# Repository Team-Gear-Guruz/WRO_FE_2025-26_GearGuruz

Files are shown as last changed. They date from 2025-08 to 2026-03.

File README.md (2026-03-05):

Engineering material
====

<p align="center">
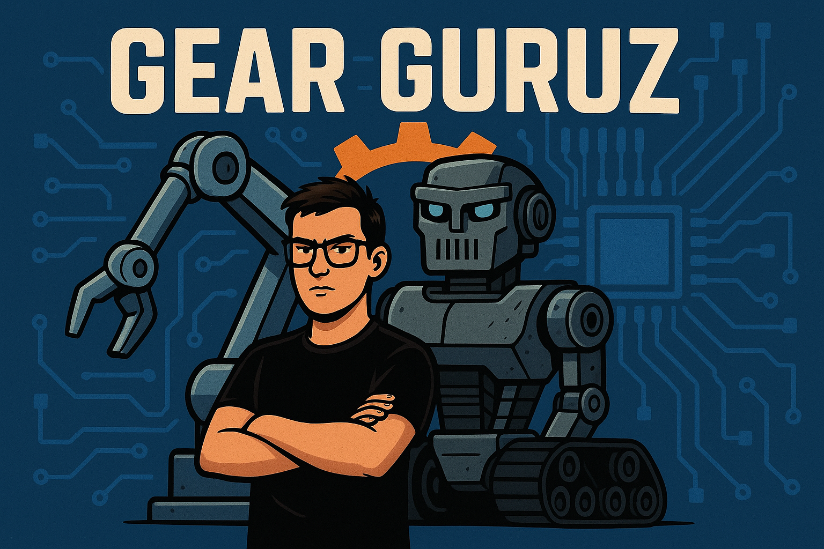
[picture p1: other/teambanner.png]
Team Banner
  
</p>

This repository contains engineering material of a self-driven vehicle's model participating in the WRO Future Engineers competition in the season 2025.

## Content of Repository

| Folder | Description |
|---|---|
| `models/`  | 3D-printable mechanical parts (sensor mounts, chassis, etc.) |
| `schemes/` | Electrical schematics and wiring diagrams |
| `src/` | Python (Raspberry Pi) → Vision, lane following, obstacle avoidance, parking logic.<br>Arduino → Motor + servo bridge (serial protocol for PWM + steering). |
| `t-photos/`| Team photos (includes one official group photo and one funny team photo) |
| `v-photos/`| Vehicle photos (6 angles: front, back, sides, top, bottom) |
| `video/` | Driving demo link or video files |
| `other/` | Documentation, datasets, hardware specs, and supporting materials |

---

##  Parts List

| Component | Quantity | Description / Role |
|---|---|---|
| Raspberry Pi 3B+ (or 4)  | 1 | Main controller, runs Python + OpenCV vision + logic |
| Arduino Uno | 1 | Low-level controller for motor + steering (PWM + servo)|
| L293D / TB6612 Driver | 1 | Motor driver IC for DC motor control |
| DC Gear Motor | 1 | Rear wheel drive motor |
| Servo Motor (MG996R) | 1 | Steering actuator (mounted on front axle) |
| HC-SR04 Ultrasonic Sensor| 6 | Obstacle detection (front, back, left, right, FL, FR)  |
| Li-on Battery 12V | 1 | Power source for electronics and motors |
| Motor Mounts / Chassis | 1 set | 3D-printed chassis parts + mounts |
| Wheels + Tires | 2–4 | Drive + steering wheels |
| Wires, Jumper cables | — | Connections between Pi, Arduino, sensors, and driver |
| Breadboard / PCB | 1 | For stable wiring and connections |
| Camera (Pi Camera / USB) | 1 | Used by Raspberry Pi for lane + obstacle detection |
| Motor 12v DC | 1 | For Moving the robot (connected to single axle) |

<!-- Parts Gallery -->
<h2> Photos of parts</h2>

<table>
  <tr>
    <td align="center">
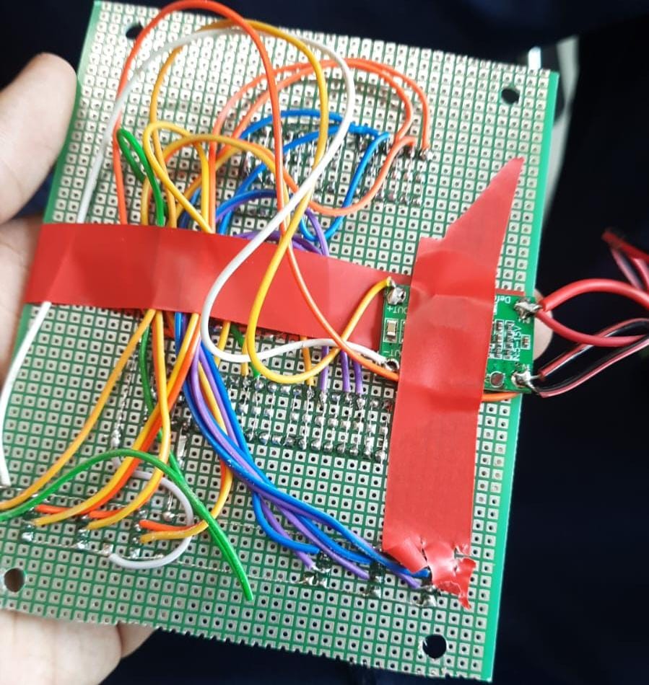
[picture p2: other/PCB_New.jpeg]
PCB
      <br/>
      <sub><b>PCB</b></sub>
    </td>
    <td align="center">
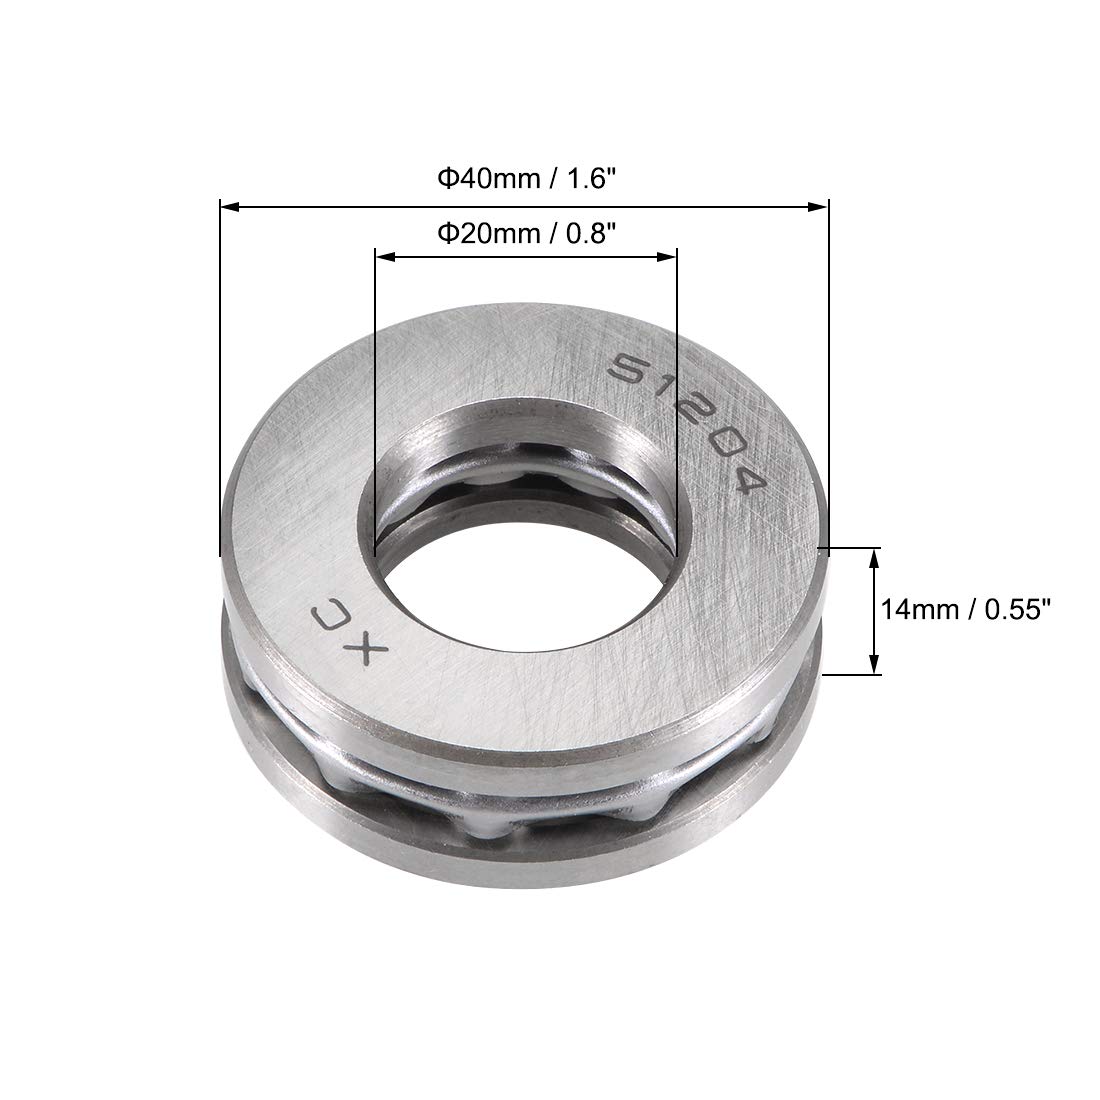
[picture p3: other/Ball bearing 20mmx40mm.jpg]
Ball bearing 1
      <br/>
      <sub><b>Ball Bearing 1</b></sub>
    </td>
    <td align="center">
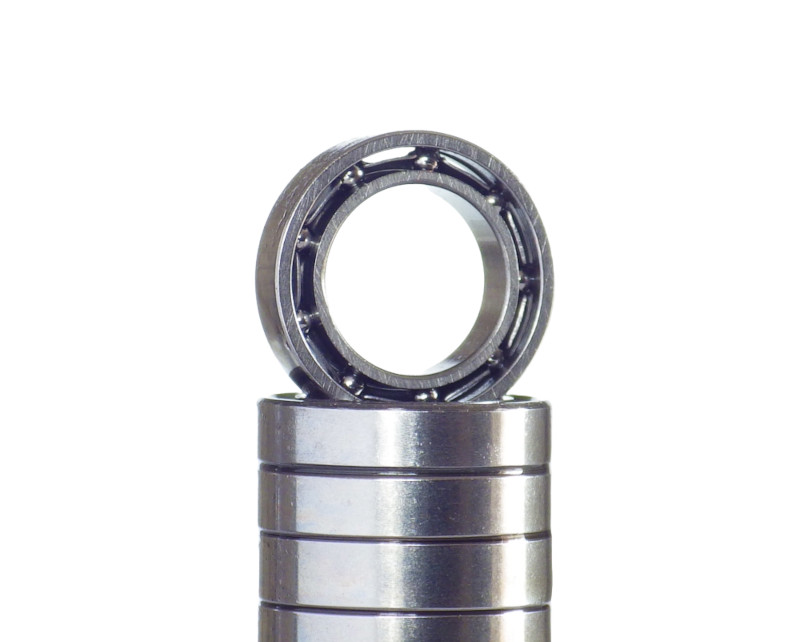
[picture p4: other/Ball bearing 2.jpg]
Ball bearing 2
      <br/>
      <sub><b>Ball Bearing 2</b></sub>
    </td>
    <td align="center">
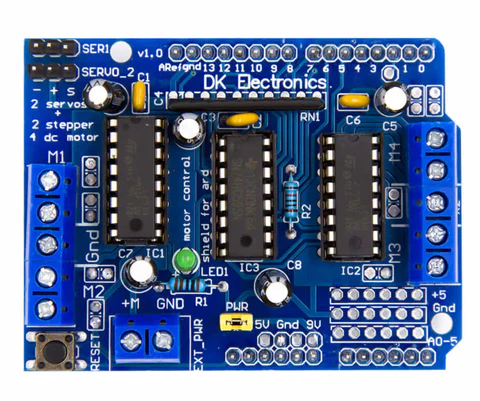
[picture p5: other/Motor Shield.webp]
Motor Shield
      <br/>
      <sub><b>Motor Shield</b></sub>
    </td>
  </tr>
</table>

## Team members

Kushal Khemani, age 16, kushal.khemani@gmail.com
Ayan Atmakuri, age 16, atmakuriayan@gmail.com

## Team Photos

##  Quick Overview

A vision-guided mini-vehicle using:

- **Raspberry Pi**: Computer vision (OpenCV), control logic (PD + FSM)  
- **Arduino Uno**: Motor and servo actuation, obstacle feedback  
- **Simple Serial Protocol**: Commands like `M <int>`, `SUS <us>`, `STOP`, `PING`  
- **Features**: Lane following, obstacle avoidance, auto-parking, HSV tuning, simulator.

# Introduction

This repository hosts the software and wiring for an autonomous robot car built for the **World Robot Olympiad 2025 – Future Engineers Challenge**.

The design leverages a **Raspberry Pi** for high-level perception and decision-making—handling lane detection, obstacle avoidance, color-coded behavior (e.g., pass red on the right, green on the left), and vision-guided parking—while an **Arduino Uno** handles real-time actuation of the DC drive motor and steering servo based on those decisions. This documentation provided a step-by-step process on how you can implement your own robot.

### System Workflow - We use this to set ground rules

1. **Vision & Perception (Raspberry Pi)**  
   - Captures camera frames and processes them for road lanes, colored markers, and parking bays.  
   - Runs a state machine with PD control logic, lap counting, and parking alignment commands.

2. **Control Communication**  
   - Sends steering (e.g., servo angle) and throttle (motor PWM) commands via serial to the Arduino.

3. **Motion Execution (Arduino)**  
   - Receives commands and outputs PWM for the motor driver (L293D/TB6612) and servo control for steering.

4. **Real World Performance**  
   - Car autonomously navigates laps, avoids obstacles, obeys color-based passing rules, executes turnarounds, and completes vision-guided parallel parking.

## 1. Mobility Management - finding what suits best 

Our vehicle’s mobility system has been engineered for robust, stable navigation across both Open and Obstacle Challenges in WRO 2025. The setup balances power, control precision, and sensor integration using reliable, competition-grade components.

### Motor Selection and Implementation

We selected a **12V DC gear motor rated at 300 RPM** for propulsion. The decision was based on:

* **High torque output**, necessary for low-speed maneuvers and quick directional changes
* Sufficient RPM to maintain speed while tracking lines or navigating walls
* Compatibility with the **L293D motor driver shield**, which allows:

  * PWM-based speed control via **digital pin D11**
  * Direction control via built-in 74HC595 shift register (internal use of D4, D7, D8, D12)

Only **Motor M1** on the shield is used, simplifying wiring and reducing interference with ultrasonic TRIG/ECHO pins.

### Steering Mechanism

Steering is handled by an **MG996R high-torque servo motor**, chosen for its:

* **Superior torque (up to 10kg.cm)**, ideal for precise control of front-wheel pivot steering
* Robust metal gears suitable for extended use and minor shocks
* Faster response time compared to standard 9g hobby servos

The servo is powered via a **dedicated buck converter set at 5V**, ensuring:

* Stable power supply without drawing current from the Arduino
* Protection against brownout during high-load movements

The servo signal is connected to **digital pin D9** and is controlled via the `Servo.h` library.

### Chassis and Component Mounting

The chassis is a **custom design** with cutouts and supports for:

* Arduino Uno + L293D Shield (stacked)
* Servo motor mounted at the front axle for steering
* Power bank or Li-ion battery for 12V supply
* Buck converter securely fixed for servo
* Ultrasonic sensors (6x) around the perimeter

The mounting design ensures:

* **Center of gravity remains low**, aiding stability
* **Balanced front-rear weight** to avoid drift or oversteer
* **Mechanical isolation** for sensor mounts to avoid vibration interference

### Engineering Principles Applied

* **Torque over speed**: The 300 RPM motor offers sufficient torque for all obstacle scenarios and allows smooth lap completion.
* **Proportional control via PWM** for both speed and steering adjustments.
* **Power isolation**: Servo draws from a separate buck, preventing logic voltage drops on Arduino.

Failsafe routines in the software monitor obstacle proximity. If all sensor readings drop below safe limits, the car **automatically reverses and adjusts angle** to prevent collision or deadlock.

## 2. Power and Sense Management - trying to be energy efficient

To enable robust autonomous operation across both the Open and Obstacle Challenges, our power and sensing systems were designed to be modular, efficient, and fail-safe. Key design goals included isolating high-power and logic domains, ensuring consistent voltage supply for sensitive components, and providing wide-angle situational awareness through sensor fusion.

---

### Power Management

#### Power Source:

The entire vehicle is powered by a **12V Li-ion battery**, chosen for its:

* High energy density
* Lightweight form factor
* Rechargeability
* Ability to sustain current surges required by motors and electronics

The battery feeds both high-power components and regulated subsystems via a **step-down (buck) converter**.

#### Voltage Regulation:

* **DC Motor (12V)**: Powered directly from the battery through an L293D motor shield.
* **Servo Motor (MG996R, 5V)**: Powered via a dedicated buck converter to ensure stable current and prevent voltage dips under load.
* **Arduino Uno & Logic Circuits**: Supplied via the 5V rail, either from USB or regulated output from the buck.
* **Raspberry Pi** (Obstacle Challenge): Powered separately or through a second buck converter, ensuring isolation from motor spikes.

This separation of power rails helps avoid brownouts, particularly during servo actuation or rapid motor speed changes. A common ground is maintained to ensure reliable sensor readings.

#### Safety Features:

* On/off switch to isolate the main supply
* Fuse protection inline with the Li-ion output
* Reverse polarity and surge protection via onboard diode

###  Sense Management

#### Sensor System:

The vehicle uses **six ultrasonic distance sensors (HC-SR04)** strategically positioned to cover:

* Forward path detection
* Side wall following and obstacle clearance
* Rear proximity awareness

These sensors were selected based on:

* Proven reliability and accuracy (2–400 cm range)
* Low cost and easy integration with Arduino
* Minimal power consumption (\~15 mA per sensor)

#### Sensor Strategy:

* **Open Challenge**: The sensors guide wall-following behavior and lap-count detection using distance thresholds and orientation cues.
* **Obstacle Challenge**: The sensors serve as secondary proximity detection, while the **Raspberry Pi + camera** handles traffic signs, colored zones, and advanced navigation through computer vision.

#### Power Consumption Considerations:

All sensors operate on 5V logic. Since each sensor draws minimal current, they are powered directly from the Arduino 5V output. The servo's power-hungry nature warranted a dedicated 5V supply via buck converter to avoid interference.

## 3. Obstacle Management - the main challenge

Obstacle management in our self-driving vehicle focuses on real-time detection, decision-making, and recovery strategies to navigate both static and dynamic obstacles with minimal latency and high reliability.

The only solution - a **hybrid approach**:

* **Ultrasonic sensors (Arduino-controlled)** for reactive proximity-based obstacle avoidance
* **Camera + Raspberry Pi (OpenCV)** for computer vision tasks such as detecting stop signs, colored zones, and “No Entry” paths

---

### Strategy Overview - what we found after a few long discussions

#### **Open Challenge (Arduino-only):**

* Use ultrasonic sensors to detect walls and gaps
* Follow the left wall to maintain direction
* Avoid close-range collisions using threshold values
* Perform a lap-count using sensor fusion
* Maintain consistent motion unless a fail-safe triggers

#### **Obstacle Challenge (Raspberry Pi + Arduino):**

* Raspberry Pi processes camera input for traffic sign recognition
* On detecting a STOP sign, Pi sends a signal to Arduino to pause
* If a colored zone or arrow sign is detected, Pi sends directional decisions
* Arduino reacts with real-time motor and steering commands
* Failsafes include “no echo” situations, timeout recovery, and realignment

---

### Flow Diagram - easy to interpret

```
[Start]
   |
   v
[Sensor Calibration]
   |
   v
[Wall Following Enabled] ←-------------------------\
   |                                              |
   v                                              |
[Obstacle Detected?] --Yes--> [Decision: Stop/Turn/Slow]
   |                                              |
  No                                              v
   |                                  [Resume Wall Following]
   v                                              |
[Zone Entry Detected?] --Yes--> [Trigger Zone Handling Logic]
   |                                              |
  No                                              v
   |                                  [Lap Count or Finish?]
   v                                              |
[Continue Movement] -----------------------------/
```

---

### Pseudocode (Obstacle Challenge) - we learnt this last year

```plaintext
Start
→ Initialize Arduino and Pi communication
→ Start camera stream and ultrasonic sensors
→ While lap count < 3:
    - Use ultrasonic sensors for wall following
    - If front obstacle distance < 15 cm:
        - Stop or steer away
    - If Pi detects STOP sign:
        - Pause 3 seconds
    - If Pi detects “turn right”:
        - Send servo signal to turn
    - If Pi detects color zone:
        - Change speed / behavior
→ After 3 laps, stop car
```

---

### Arduino Code Snippet (Obstacle Handling Logic) - OOP

// Inside loop()

```cpp
long distFC = readDistance(TRIG_FC, ECHO_FC);
long distL = readDistance(TRIG_L, ECHO_L);
long distR = readDistance(TRIG_R, ECHO_R);

// Wall following logic
if (distL < 15) {
  turnRight();
} else if (distL > 30) {
  turnLeft();
} else {
  goStraight();
}

// Obstacle ahead
if (distFC < 12) {
  stopCar();
  delay(800);
  turnRight();  // Basic evasive action
  delay(400);
}
```

---

### Raspberry Pi Role (Computer Vision)

The Pi runs OpenCV-based code to:

* Detect red signs
* Recognize arrows for directional instructions
* Identify colored zones using HSV masks

After classification, the Pi sends command signals to Arduino via serial:

* `"STOP"`, `"LEFT"`, `"RIGHT"`, etc.

The Arduino interprets these and adjusts movement accordingly.

---

### Failsafe Mechanisms

* **No echo recovery**: If no echo is received from a sensor for more than 3 reads, the car slows down and centers.
* **Stuck detection**: If the car hasn't moved in distance (based on rear sensors), it reverses for 1 second and retries.
* **Soft timeout**: If a lap takes longer than 2 minutes, the system logs an alert.
* **Reversing**: The car reverses if it is less than 15 cm from an obstacle.

# Arduino Pin Mapping for Self-Driving Car (WRO 2025) 

**This is what we decided upon...**

### 🔧 Motor (M1 via L293D Shield)
- **Speed (PWM):** `D11`  
- **Direction:** Handled internally by the shield’s 74HC595  
  *(Uses internal pins D4, D7, D8, D12 — do not control directly)*

---

### Servo Motor
- **Signal Pin:** `D9`

---

### Ultrasonic Sensors (6 Total)
> Echo lines are placed on analog pins `A0–A5` for cleaner signal and to free digital pins.  
> Trigger lines are assigned to available digital pins.

# Unit Testing For Arduino

These are standalone Arduino sketches to test individual subsystems (servo, motor, ultrasonic sensors) before integrating them together.  
Each can be copied into the Arduino IDE and uploaded separately.

### 1) Servo Sweep (D9)

Moves the steering **servo** smoothly from 0°→180°→0°.  
**Important:** MG996R needs its own 5–6 V supply (≥3 A). Do not power from the Arduino 5 V pin.
Errors I made - did not use a buck converter to supply constant voltage and amps. This caused stuttering in the steering.

```cpp
#include <Servo.h>

Servo myServo;

void setup() {
  myServo.attach(9);   // Servo signal on D9 (power from external 5–6 V)
}

void loop() {
  // Sweep 0° -> 180°
  for (int pos = 0; pos <= 180; pos += 5) {
    myServo.write(pos);
    delay(50);
  }
  // Sweep back 180° -> 0°
  for (int pos = 180; pos >= 0; pos -= 5) {
    myServo.write(pos);
    delay(50);
  }
}

```
### 2) DC Motor on L293D Shield (M1)

Drives the M1 motor channel forward, stop, reverse, stop.

Note: generic L293D shields vary. This code assumes M1_DIR on D12 and M1_PWM on D3.
If your shield uses different pins, update the defines.
Errors I made - used the pins on the arduino that the motor shield was dependent on.
```cpp
// Test Motor at M1 on L293D Shield
int M1_DIR = 12;  // Direction pin for M1 (check your shield!)
int M1_PWM = 3;   // PWM pin for M1 speed

void setup() {
  pinMode(M1_DIR, OUTPUT);
  pinMode(M1_PWM, OUTPUT);
}

void loop() {
  // Forward
  digitalWrite(M1_DIR, HIGH);
  analogWrite(M1_PWM, 200);  // Speed (0-255)
  delay(2000);

  // Stop
  analogWrite(M1_PWM, 0);
  delay(1000);

  // Reverse
  digitalWrite(M1_DIR, LOW);
  analogWrite(M1_PWM, 200);
  delay(2000);

  // Stop
  analogWrite(M1_PWM, 0);
  delay(1000);
}
```  
### 3) Six Ultrasonic Sensors (HC-SR04)

Reads Front, Back, Left, Right, Diagonal-Front-Left, Diagonal-Front-Right.
All sensors share VCC → 5 V and GND → GND, each has its own TRIG/ECHO pins.
Errors I made - connecting the trig pins in one digital pin (for sequential reading). This made the program complex and led to crashing.
```cpp
// ------------------- Pin mappings -------------------
// ---- Ultrasonic Sensors ----
struct Ultrasonic {
  uint8_t trigPin;
  uint8_t echoPin;
  const char* name;
};

// Define all sensors with mapping
Ultrasonic sensors[] = {
  {2,  A0, "Front-Center"},
  {3,  A1, "Front-Left Diagonal"},
  {5,  A2, "Front-Right Diagonal"},
  {6,  A3, "Left"},
  {10, A4, "Right"},
  {13, A5, "Back"}
};

long getDistance(uint8_t trigPin, uint8_t echoPin) {
  // Send trigger pulse
  digitalWrite(trigPin, LOW);
  delayMicroseconds(2);
  digitalWrite(trigPin, HIGH);
  delayMicroseconds(10);
  digitalWrite(trigPin, LOW);

  // Read echo time
  long duration = pulseIn(echoPin, HIGH, 20000); // timeout = 20ms (~3.4m range)

  // Convert to distance in cm
  long distance = duration * 0.034 / 2;
  return distance;
}

void setup() {
  Serial.begin(9600);

  // Initialize pins
  for (auto &s : sensors) {
    pinMode(s.trigPin, OUTPUT);
    pinMode(s.echoPin, INPUT);
  }

  Serial.println("Ultrasonic Sensor Test Started...");
}

void loop() {
  for (auto &s : sensors) {
    long d = getDistance(s.trigPin, s.echoPin);
    Serial.print(s.name);
    Serial.print(": ");
    if (d == 0) Serial.println("Out of range");
    else Serial.print(d), Serial.println(" cm");
  }

  Serial.println("--------------------");
  delay(500); // wait before next reading
}

```  
🥳 Gotchas

Servo power: MG996R is high-torque; use a separate 5–6 V buck (≥3–5 A).

Motor shield pinouts: Check your shield silkscreen; some use D11/D3 for M1.

Grounding: Arduino GND, motor shield GND, buck GND, servo GND, and sensor GND must all be connected together.

Ultrasonic max range: 400 cm in the serial monitor means “no object detected.”

### 4) Modular Testing Code - because why not.
This code will involve all components required to run the robot in the first round.

It’s menu-driven over the Serial Monitor:

Press 1 → Servo sweep test

Press 2 → Motor forward/stop/reverse test

Press 3 → Live ultrasonic scan (all six)

Press 4 → Simple safety drive (forward, stop if front < 25 cm)

Press s → Stop motor immediately

Press h → Help menu

```cpp
/*
  Modular Test Suite: Motor (L293D M1) + Servo (D10) + 6x Ultrasonic
  - Board: Arduino Uno + Generic L293D Motor Shield
  - Motor: M1 (AFMotor abstracts shield pins)
  - Servo: MG996R signal on D10 (POWER FROM 5–6 V BUCK, not Arduino 5V!)
  - Ultrasonic: 6x HC-SR04, shared 5V/GND, individual TRIG/ECHO pins

  Controls (Serial Monitor @115200, "No line ending"):
    1 : Servo sweep
    2 : Motor test (FWD, STOP, REV)
    3 : Ultrasonic live scan (all 6)
    4 : Safety drive (forward; stop if front < 25 cm)
    s : Stop motor now
    h : Help
*/

#include <AFMotor.h>
#include <Servo.h>

// ------------------- Motor (L293D shield, M1) -------------------
AF_DCMotor motor1(1);   // M1 port on the shield

// ------------------- Servo (signal on D10) ----------------------
Servo steering;
const int SERVO_PIN = 10;
const int SERVO_CENTER = 90;
const int SERVO_SWEEP = 40; // ±40° from center

// ------------------- Ultrasonic pins ----------------------------
#define TRIG_F   2
#define ECHO_F   4

#define TRIG_B   5
#define ECHO_B   6

#define TRIG_L   7
#define ECHO_L   8

#define TRIG_R   A0   // D14
#define ECHO_R   A1   // D15

#define TRIG_DFL A2   // D16
#define ECHO_DFL A3   // D17

#define TRIG_DFR A4   // D18
#define ECHO_DFR A5   // D19

// ------------------- Modes --------------------------------------
enum Mode : uint8_t {
  IDLE = 0,
  SERVO_SWEEP_MODE,
  MOTOR_TEST_MODE,
  ULTRA_SCAN_MODE,
  SAFETY_DRIVE_MODE
};

Mode mode = IDLE;

// ------------------- Helpers ------------------------------------
long readDistanceCM(int trigPin, int echoPin) {
  digitalWrite(trigPin, LOW);
  delayMicroseconds(2);
  digitalWrite(trigPin, HIGH);
  delayMicroseconds(10);
  digitalWrite(trigPin, LOW);

  unsigned long duration = pulseIn(echoPin, HIGH, 30000UL); // timeout 30ms
  if (duration == 0) return 400; // no echo within window
  return duration / 58;          // µs → cm
}

struct Distances {
  long F, B, L, R, DFL, DFR;
};

Distances readAll() {
  Distances d;
  d.F   = readDistanceCM(TRIG_F,   ECHO_F);
  d.B   = readDistanceCM(TRIG_B,   ECHO_B);
  d.L   = readDistanceCM(TRIG_L,   ECHO_L);
  d.R   = readDistanceCM(TRIG_R,   ECHO_R);
  d.DFL = readDistanceCM(TRIG_DFL, ECHO_DFL);
  d.DFR = readDistanceCM(TRIG_DFR, ECHO_DFR);
  return d;
}

void printAll(const Distances& d) {
  Serial.print("F: ");   Serial.print(d.F);   Serial.print("  ");
  Serial.print("B: ");   Serial.print(d.B);   Serial.print("  ");
  Serial.print("L: ");   Serial.print(d.L);   Serial.print("  ");
  Serial.print("R: ");   Serial.print(d.R);   Serial.print("  ");
  Serial.print("DFL: "); Serial.print(d.DFL); Serial.print("  ");
  Serial.print("DFR: "); Serial.println(d.DFR);
}

// ------------------- Motor control wrappers ---------------------
void motorStop() {
  motor1.run(RELEASE);
}

void motorForward(uint8_t speed255) {
  motor1.setSpeed(speed255);
  motor1.run(FORWARD);
}

void motorBackward(uint8_t speed255) {
  motor1.setSpeed(speed255);
  motor1.run(BACKWARD);
}

// ------------------- UI -----------------------------------------
void printHelp() {
  Serial.println(F("\n=== Test Suite Controls ==="));
  Serial.println(F("1 : Servo sweep"));
  Serial.println(F("2 : Motor test (forward/stop/reverse)"));
  Serial.println(F("3 : Ultrasonic live scan"));
  Serial.println(F("4 : Safety drive (stop if front < 25 cm)"));
  Serial.println(F("s : Stop motor"));
  Serial.println(F("h : Help\n"));
}

void setMode(Mode m) {
  mode = m;
  switch (mode) {
    case IDLE:               Serial.println(F("[MODE] IDLE")); break;
    case SERVO_SWEEP_MODE:   Serial.println(F("[MODE] SERVO SWEEP")); break;
    case MOTOR_TEST_MODE:    Serial.println(F("[MODE] MOTOR TEST")); break;
    case ULTRA_SCAN_MODE:    Serial.println(F("[MODE] ULTRASONIC SCAN")); break;
    case SAFETY_DRIVE_MODE:  Serial.println(F("[MODE] SAFETY DRIVE")); break;
  }
}

// ------------------- Setup --------------------------------------
void setup() {
  Serial.begin(115200);

  // Servo
  steering.attach(SERVO_PIN);
  steering.write(SERVO_CENTER);

  // Motor
  motorStop();           // ensure stopped
  motor1.setSpeed(0);

  // Ultrasonic pinModes
  pinMode(TRIG_F, OUTPUT);   pinMode(ECHO_F, INPUT);
  pinMode(TRIG_B, OUTPUT);   pinMode(ECHO_B, INPUT);
  pinMode(TRIG_L, OUTPUT);   pinMode(ECHO_L, INPUT);
  pinMode(TRIG_R, OUTPUT);   pinMode(ECHO_R, INPUT);
  pinMode(TRIG_DFL, OUTPUT); pinMode(ECHO_DFL, INPUT);
  pinMode(TRIG_DFR, OUTPUT); pinMode(ECHO_DFR, INPUT);

  printHelp();
  setMode(IDLE);
}

// ------------------- Mode state vars ----------------------------
unsigned long t0 = 0;
int sweepDir = +1;
int servoPos = SERVO_CENTER;

// For motor test steps
uint8_t motorStep = 0;
unsigned long motorTimer = 0;

// ------------------- Loop ---------------------------------------
void loop() {
  // ---- Serial command handling ----
  if (Serial.available()) {
    char c = Serial.read();
    if (c == '1') setMode(SERVO_SWEEP_MODE);
    else if (c == '2') { motorStep = 0; motorTimer = 0; setMode(MOTOR_TEST_MODE); }
    else if (c == '3') setMode(ULTRA_SCAN_MODE);
    else if (c == '4') setMode(SAFETY_DRIVE_MODE);
    else if (c == 's') { motorStop(); Serial.println(F("[MOTOR] STOP")); }
    else if (c == 'h') printHelp();
  }

  // ---- Mode behaviors ----
  switch (mode) {
    case IDLE: {
      // idle: keep things safe
      motorStop();
      steering.write(SERVO_CENTER);
    } break;

    case SERVO_SWEEP_MODE: {
      // Non-blocking sweep: update every 20 ms
      unsigned long now = millis();
      if (now - t0 >= 20) {
        t0 = now;
        servoPos += sweepDir * 2;  // speed of sweep
        if (servoPos >= SERVO_CENTER + SERVO_SWEEP) { servoPos = SERVO_CENTER + SERVO_SWEEP; sweepDir = -1; }
        if (servoPos <= SERVO_CENTER - SERVO_SWEEP) { servoPos = SERVO_CENTER - SERVO_SWEEP; sweepDir = +1; }
        steering.write(servoPos);
      }
    } break;

    case MOTOR_TEST_MODE: {
      // Step through: FWD 2s → STOP 1s → REV 2s → STOP 1s → repeat
      unsigned long now = millis();
      if (motorStep == 0) {
        motorForward(200);
        Serial.println(F("[MOTOR] FORWARD @200"));
        motorTimer = now;
        motorStep = 1;
      } else if (motorStep == 1 && now - motorTimer >= 2000) {
        motorStop();
        Serial.println(F("[MOTOR] STOP"));
        motorTimer = now;
        motorStep = 2;
      } else if (motorStep == 2 && now - motorTimer >= 1000) {
        motorBackward(200);
        Serial.println(F("[MOTOR] BACKWARD @200"));
        motorTimer = now;
        motorStep = 3;
      } else if (motorStep == 3 && now - motorTimer >= 2000) {
        motorStop();
        Serial.println(F("[MOTOR] STOP"));
        motorTimer = now;
        motorStep = 4;
      } else if (motorStep == 4 && now - motorTimer >= 1000) {
        motorStep = 0; // loop again
      }
    } break;

    case ULTRA_SCAN_MODE: {
      // Print all sensor distances ~10 Hz
      static unsigned long lastPrint = 0;
      unsigned long now = millis();
      if (now - lastPrint >= 100) {
        lastPrint = now;
        Distances d = readAll();
        printAll(d);
      }
    } break;

    case SAFETY_DRIVE_MODE: {
      // Drive forward slowly; stop if front < 25 cm
      static unsigned long lastChk = 0;
      unsigned long now = millis();
      if (now - lastChk >= 100) {
        lastChk = now;
        long f = readDistanceCM(TRIG_F, ECHO_F);
        Serial.print(F("Front(cm): ")); Serial.println(f);
        if (f < 25) {
          motorStop();
          Serial.println(F("[SAFETY] Obstacle close → STOP"));
        } else {
          motorForward(140); // gentle cruise
        }
      }
      // Keep servo centered during this simple test
      steering.write(SERVO_CENTER);
    } break;
  }
}

```

  Wiring Notes:
  - Motor: connect to M1 on L293D shield; supply 6–12 V to shield VM/EXT PWR; GND common with Arduino.
  - Servo: D10 signal; POWER from separate 5–6 V buck (≥3–5 A). Tie buck GND to Arduino GND.
  - Ultrasonic: All VCC → 5 V, all GND → GND. TRIG/ECHO as defined above.
  - Common Ground: Battery –, shield GND, Arduino GND, both buck GNDs, sensor GND, servo GND MUST be common.

# Arduino Code – Square Track 3-Lap Challenge

This Arduino code powers a self-driving robot car to autonomously complete **3 laps on a square track** that contains both **interior and exterior walls**. It uses **6 ultrasonic sensors** to detect obstacles and implements a **left-wall-following algorithm** for navigation.

---

## Navigation Strategy

- **Wall Following Rule:** Left-hand rule – always keep the left wall within a specific distance range.
- **Obstacle Avoidance:** Uses `Front-Center`, `Left`, and `Right` sensors to detect and steer around walls.
- **Lap Detection:** When the robot re-enters a specific sensor pattern near the start zone (e.g., wall in front but no wall on left), a lap is counted.
- **Goal:** Complete 3 full laps and stop.

---

## Pin Configuration

| Component | TRIG (Digital) | ECHO (Analog) |
|---|---|---|
| Front-Center (FC) | D2 | A0 |
| Front-Left Diagonal  | D3 | A1 |
| Front-Right Diagonal | D5 | A2 |
| Left (L) | D6 | A3 |
| Right (R) | D10 | A4 |
| Back (B) | D13 | A5 |

- **Motor (M1):** PWM on D11 (Direction handled by L293D shield)
- **Servo:** Signal on D9

---

## Arduino Code with Explanation

### 1. Pin Mapping and Includes

We define all the pin assignments and include the Servo library to control the steering mechanism.

```cpp
#define TRIG_FC 2
#define ECHO_FC A0
#define TRIG_FLD 7
#define ECHO_FLD A1
#define TRIG_FRD 8
#define ECHO_FRD A2
#define TRIG_L 10
#define ECHO_L A3
#define TRIG_R 12
#define ECHO_R A4
#define TRIG_B 13
#define ECHO_B A5

#define MOTOR_PWM 11
#define SERVO_PIN 9
#define STBY 4 // used internally by the shield

#include <Servo.h>
````

---

### 2. Global Variables and Distance Reader

* `lapCount`: Tracks completed laps.
* `inStartZone`: Used to avoid double-counting laps.
* `readDistance()`: Generic ultrasonic reader using TRIG/ECHO logic.

```cpp
Servo steering;

int lapCount = 0;
bool inStartZone = false;
unsigned long lastLapTime = 0;

long readDistance(int trigPin, int echoPin) {
  digitalWrite(trigPin, LOW); delayMicroseconds(2);
  digitalWrite(trigPin, HIGH); delayMicroseconds(10);
  digitalWrite(trigPin, LOW);

  long duration = pulseIn(echoPin, HIGH, 30000); // 30ms timeout
  if (duration == 0) return 400;
  return duration / 58;
}
```

---

### 3. Basic Movement Commands

These functions control the car's direction and speed using the motor and servo.

```cpp
void moveForward() {
  analogWrite(MOTOR_PWM, 180);  // Set motor speed
}

void turnLeft() {
  steering.write(120);  // Servo turn left
}

void turnRight() {
  steering.write(60);   // Servo turn right
}

void goStraight() {
  steering.write(90);   // Servo center
}

void stopCar() {
  analogWrite(MOTOR_PWM, 0);  // Stop motor
}
```

---

### 4. Setup Routine

Sets pin modes and prepares the motor and servo.

```cpp
void setup() {
  Serial.begin(9600);

  pinMode(TRIG_FC, OUTPUT); pinMode(ECHO_FC, INPUT);
  pinMode(TRIG_FLD, OUTPUT); pinMode(ECHO_FLD, INPUT);
  pinMode(TRIG_FRD, OUTPUT); pinMode(ECHO_FRD, INPUT);
  pinMode(TRIG_L, OUTPUT); pinMode(ECHO_L, INPUT);
  pinMode(TRIG_R, OUTPUT); pinMode(ECHO_R, INPUT);
  pinMode(TRIG_B, OUTPUT); pinMode(ECHO_B, INPUT);

  pinMode(MOTOR_PWM, OUTPUT);
  steering.attach(SERVO_PIN);
  goStraight();  // Default orientation
}
```

---

### 5. Main Navigation Loop

The loop reads distances and makes steering decisions. It also monitors lap count based on a “start zone” condition.

```cpp
void loop() {
  long distFC = readDistance(TRIG_FC, ECHO_FC);
  long distL = readDistance(TRIG_L, ECHO_L);
  long distR = readDistance(TRIG_R, ECHO_R);
```

#### Lap Detection Logic

This logic ensures that a lap is only counted when the robot passes through a specific condition: wall ahead but no left wall.

```cpp
  if (distFC < 20 && distL > 50 && (millis() - lastLapTime > 3000)) {
    if (!inStartZone) {
      lapCount++;
      Serial.print("Lap Completed: "); Serial.println(lapCount);
      lastLapTime = millis();
      inStartZone = true;
    }
  } else if (distFC > 30) {
    inStartZone = false;
  }
```

#### Wall-Following Steering

Uses distance from the left wall to steer the car.

```cpp
  if (distL < 15) {
    turnRight();  // Too close to wall
  } else if (distL > 30) {
    turnLeft();   // Too far from wall
  } else {
    goStraight();
  }

  moveForward();  // Keep moving
```

#### Stop After 3 Laps

```cpp
  if (lapCount >= 3) {
    stopCar();
    while (true) {
      Serial.println("Mission Complete!");
      delay(1000);
    }
  }

  delay(100);  // Loop pacing
}
```

---

## Customization Tips

| Goal | What to Adjust |
| --- | --- |
| More precise turning | Tune `steering.write()` values |
| Better lap detection | Modify `distFC` and `distL` thresholds |
| Change wall-following side | Replace `distL` logic with `distR` |
| Avoid diagonal corners | Use FLD / FRD for early turns |

---

## Optional Enhancements

* Add line sensors or camera for finish line detection
* Use PID for better steering control
* Switch to right-wall following by updating logic

---
FULL CODE (With Revisons)- 
```cpp
/*
  WRO 2025 – Open Challenge
  Full Obstacle Avoidance (Potential-Field Style) + PD Steering & Proportional Speed
  Hardware: Arduino UNO + Adafruit Motor Shield v1 (L293D) + 1x DC Motor (M1) + Servo (D9) 

/*
  WRO 2025 – Open Challenge with Lap Counting
*/

#include <Servo.h>
#include <AFMotor.h>

// ---------- Pin Map (updated) ----------
#define TRIG_FC 13    // Front-Center TRIG moved to D13
#define ECHO_FC A5    // Front-Center ECHO moved to A5
#define TRIG_FLD 3    // Front-Left Diag TRIG
#define ECHO_FLD A1
#define TRIG_FRD 5    // Front-Right Diag TRIG
#define ECHO_FRD A2
#define TRIG_L 6      // Left TRIG
#define ECHO_L A3
#define TRIG_R 10     // Right TRIG
#define ECHO_R A4

#define SWITCH_PIN A0 // Start switch: one leg to A0, other to GND
#define SERVO_PIN 9   // Steering servo (D9)

// ---------- Hardware ----------
AF_DCMotor motor(1);    // M1 on L293D shield v1
Servo steering;

// ---------- Tunables ----------
const uint16_t ECHO_TIMEOUT_US = 30000;  // ~5 m

const int      MAX_STEER_DEG   = 60;
const float    KP_STEER        = 1.9f;
const float    KD_STEER        = 0.25f;

const int      BASE_SPEED      = 240;
const int      MIN_SPEED       = 120;
const int      REVERSE_SPEED   = 160;
const int      CLEAR_FAST_CM   = 90;
const int      CLEAR_SLOW_CM   = 20;

const int      FRONT_REVERSE_CM= 10;     // reverse if FC < 10 cm
const int      HARD_BLOCK_CM   = 14;     // reverse if tight ahead/diagonals
const int      SIDE_PUSH_START = 60;

const float    K_FRONT         = 1.9f;
const float    K_DIAG          = 1.7f;
const float    K_SIDE          = 1.6f;

const float    ALPHA_SMOOTH    = 0.20f;
const bool     INVERT_MOTOR    = false;

// ---------- State (smoothed distances) ----------
float dFCf=200, dFLDf=200, dFRDf=200, dLf=200, dRf=200;
float prevFy = 0.0f;

// ---------- Lap counting ----------
unsigned long lastLapTime = 0;
int lapCount = 0;
const int maxLaps = 3;
const unsigned long lapCooldownMs = 20000; // 20s (your lap ~35s)

// ---------- Helpers ----------
long readDistanceOnce(uint8_t trig, uint8_t echo) {
  pinMode(trig, OUTPUT);
  pinMode(echo, INPUT);

  digitalWrite(trig, LOW);  delayMicroseconds(2);
  digitalWrite(trig, HIGH); delayMicroseconds(10);
  digitalWrite(trig, LOW);

  unsigned long dur = pulseIn(echo, HIGH, ECHO_TIMEOUT_US);
  if (dur == 0) return 400;       // treat as far (no echo)
  return (long)(dur / 58);        // us -> cm
}

long readDistanceMedian3(uint8_t trig, uint8_t echo) {
  long a = readDistanceOnce(trig, echo);
  long b = readDistanceOnce(trig, echo);
  long c = readDistanceOnce(trig, echo);
  if (a > b) { long t=a; a=b; b=t; }
  if (b > c) { long t=b; b=c; c=t; }
  if (a > b) { long t=a; a=b; b=t; }
  return b;
}

template<typename T>
T clamp(T v, T lo, T hi) { return (v < lo) ? lo : (v > hi) ? hi : v; }

void setSteerDeg(int delta) { // -MAX..+MAX relative to center (90°)
  delta = clamp(delta, -MAX_STEER_DEG, MAX_STEER_DEG);
  const int center_us = 1500;
  const float us_per_deg = 11.0f;     // tune if needed (10–12 typical)
  int pulse = center_us + (int)(delta * us_per_deg);
  steering.writeMicroseconds(clamp(pulse, 1000, 2000));
}

void driveForward(uint8_t spd) {
  motor.setSpeed(spd);
  if (INVERT_MOTOR) motor.run(BACKWARD);
  else              motor.run(FORWARD);
}

void driveBackward(uint8_t spd) {
  motor.setSpeed(spd);
  if (INVERT_MOTOR) motor.run(FORWARD);
  else              motor.run(BACKWARD);
}

void driveStop() {
  motor.setSpeed(0);
  motor.run(RELEASE);
}

// Reverse 1.5s -> steer to freer side 60° -> forward 0.4s -> straighten
void reverseAndAdjust(bool steerRight) {
  driveBackward(REVERSE_SPEED);
  delay(1500);
  driveStop();

  setSteerDeg(steerRight ? +MAX_STEER_DEG : -MAX_STEER_DEG);
  delay(120);
  driveForward(MIN_SPEED);
  delay(400);
  driveStop();
  setSteerDeg(0);
}

int mapToSpeed(long clear_cm) {
  if (clear_cm <= CLEAR_SLOW_CM) return MIN_SPEED;
  if (clear_cm >= CLEAR_FAST_CM) return BASE_SPEED;
  float t = float(clear_cm - CLEAR_SLOW_CM) / float(CLEAR_FAST_CM - CLEAR_SLOW_CM);
  int spd = (int)(MIN_SPEED + t * (BASE_SPEED - MIN_SPEED));
  return clamp(spd, MIN_SPEED, BASE_SPEED);
}

float repulse(float d_cm, float range_cm, float k) {
  if (d_cm >= range_cm) return 0.0f;
  float s = 1.0f - (d_cm / range_cm);
  if (s < 0) s = 0;
  return k * s; // smooth, bounded
}

void waitForSwitch() {
  // Button wired: A0 <-> GND (active LOW). Use internal pull-up.
  pinMode(SWITCH_PIN, INPUT_PULLUP);
  // Wait until pressed (LOW) then released (HIGH) to start
  while (digitalRead(SWITCH_PIN) == HIGH) { delay(10); } // wait press
  delay(150); // debounce
  while (digitalRead(SWITCH_PIN) == LOW) { delay(10); }  // wait release
  delay(150); // debounce
}

// ---------- Setup ----------
void setup() {
  Serial.begin(115200);

  steering.attach(SERVO_PIN);
  setSteerDeg(0);

  motor.setSpeed(0);
  motor.run(RELEASE);

  // Wait for start switch on A0
  waitForSwitch();

  // Seed filters
  dFCf  = readDistanceMedian3(TRIG_FC,  ECHO_FC);
  dFLDf = readDistanceMedian3(TRIG_FLD, ECHO_FLD);
  dFRDf = readDistanceMedian3(TRIG_FRD, ECHO_FRD);
  dLf   = readDistanceMedian3(TRIG_L,   ECHO_L);
  dRf   = readDistanceMedian3(TRIG_R,   ECHO_R);
}

// ---------- Main Loop ----------
void loop() {
  // 1) Read & smooth distances
  long dFC  = readDistanceMedian3(TRIG_FC,  ECHO

```
## **Now we shall be using a Raspberry Pi too.**

# Getting Started

I had absolutely no idea how to use a Raspberry Pi when we first started working with it. At the beginning, even basic tasks like flashing the OS onto an SD card or connecting it to a monitor felt overwhelming. To figuring things out, relying on a few YouTube tutorials that broke the process down step by step. Slowly, by following along with these resources, I gained confidence and were able to start experimenting with the Pi ourselves.

**Helpful videos we used:**

1. [Guide on setting up a Raspberry Pi 4](https://www.youtube.com/watch?v=ntaXWS8Lk34)
2. [Installing Raspberry Pi OS](https://www.youtube.com/watch?v=ntLJmHOJ0ME)
3. [Beginner-friendly tutorial on GPIO pins](https://www.youtube.com/watch?v=H1lxZweM52U)

Since I had just moved houses and all my electronics were still at my old place, I had to figure out how to use the Raspberry Pi without a keyboard or monitor. I ended up setting it up for headless operation, which means accessing it remotely from my laptop over Wi-Fi. By enabling SSH and using a tool like PuTTY or the built-in terminal, I could control the Pi entirely from my computer. This allowed me to run commands, install software, and experiment with projects without needing the physical peripherals. It was a lifesaver while I waited to get my setup back from the old house.

This is what I did - 

### **Step 1: Download Raspberry Pi OS**

1. Go to the [Raspberry Pi Software page](https://www.raspberrypi.com/software/).
2. Download **Raspberry Pi OS Lite** (no desktop required, smaller and faster for headless use).

---

### **Step 2: Flash the OS to the SD Card**

1. Download and install **Raspberry Pi Imager** or **Balena Etcher** on your computer.
2. Insert your SD card.
3. Open the imager/etcher → select the OS image → select the SD card → flash.
4. Wait until the process finishes.

---

### **Step 3: Enable SSH**

1. After flashing, open the SD card folder on your computer.
2. In the **root directory** (the main folder), create a blank file named:

```
ssh
```

(no extension, all lowercase).
3\. This will allow you to remotely access the Pi using SSH.

---

### **Step 4: Connect to Wi-Fi**

1. In the same SD card root directory, create a file called:

```
wpa_supplicant.conf
```

2. Open it with a text editor and add:

```conf
country=IN
ctrl_interface=DIR=/var/run/wpa_supplicant GROUP=netdev
update_config=1

network={
    ssid="YOUR_WIFI_SSID"
    psk="YOUR_WIFI_PASSWORD"
    key_mgmt=WPA-PSK
}
```

3. Replace `YOUR_WIFI_SSID` and `YOUR_WIFI_PASSWORD` with your network info.
4. Save the file. This will let your Pi connect to Wi-Fi on boot.

---

### **Step 5: Boot the Raspberry Pi**

1. Insert the SD card into the Pi.
2. Connect power.
3. Wait 2–3 minutes for it to boot and connect to Wi-Fi.

---

### **Step 6: Find the Pi’s IP Address**

* Option 1: Log into your router and check connected devices.
* Option 2: Use a phone app like **Fing** to scan your Wi-Fi network.
* Look for a device named `raspberrypi`. Note the IP address (e.g., `192.168.1.5`).

---

### **Step 7: Connect via SSH**

* **On Windows:** Use [PuTTY](https://www.putty.org/)

  1. Open PuTTY → enter the Pi’s IP → Port = 22 → SSH → Open.
  2. Login with username: `pi`, password: `raspberry`.

* **On Mac/Linux:** Open Terminal and type:

```bash
ssh pi@<Pi_IP_address>
```

(e.g., `ssh pi@192.168.1.5`)

* Enter password: `raspberry`.

---

### **Step 8: Update Your Pi**

Once connected, run:

```bash
sudo apt update
sudo apt upgrade -y
```

This ensures your Pi has the latest software.

## Setting up VSCode

### **Step 1: Install VS Code and Remote SSH Extension**

1. Make sure **Visual Studio Code** is installed on your computer: [VS Code Download](https://code.visualstudio.com/).
2. Open VS Code → go to **Extensions (Ctrl+Shift+X)** → search for **Remote - SSH** → install it.

---

### **Step 2: Connect VS Code to Raspberry Pi via SSH**

1. Press `F1` → type **Remote-SSH: Connect to Host…** → select **Add New SSH Host**.
2. Enter your SSH connection:

```bash
ssh pi@<Pi_IP_address>
```

Example: `ssh pi@192.168.1.5`
3\. Choose the default SSH config file location when prompted.
4\. Once added, select the host → VS Code will open a new window connected to your Pi.
5\. Enter password: `raspberry`.

Now your VS Code is **directly running on the Pi**, even though it’s headless.

---

### **Step 3: Open or Create a Project**

1. In the new VS Code window, go to **File → Open Folder** → navigate to a folder on your Pi (e.g., `/home/pi/projects`).
2. You can now **create new Python, C++, or Arduino files** here.

---

### **Step 4: Upload/Run Code**

* Any file you save in VS Code is automatically on your Pi.
* To run Python code, open the terminal in VS Code (\`Ctrl+\`\`) and run:

```bash
python3 myfile.py
```

* For C++ or other languages, you can compile/run the code directly in the terminal.

---

### **Step 5 (Optional): Sync Local Folder to Pi**

If you want to edit files locally and upload automatically:

1. Install **SFTP extension** in VS Code.
2. Configure it with your Pi’s IP, username `pi`, password `raspberry`.
3. Every time you save locally, it uploads to the Pi automatically.

# Unit Testing For Raspberry Pi
### 1) Camera Testing File
```py
from picamera2 import Picamera2
import cv2

picam2 = Picamera2()
picam2.preview_configuration.main.size = (640, 480)
picam2.preview_configuration.main.format = "RGB888"
picam2.configure("preview")

picam2.start()

while True:
    frame = picam2.capture_array()
    cv2.imshow("Camera", frame)
    if cv2.waitKey(1) & 0xFF == ord('q'):
        break

cv2.destroyAllWindows()

```
### 2) Using Raspberry Pi to output to Arduino

```cpp
#include <AFMotor.h>   // For L293D motor shield
#include <Servo.h>

AF_DCMotor motor(1);   // Motor connected to M1 on L293D shield
Servo steering;        // Steering servo

// Servo center values (adjust for your robot’s alignment)
const int SERVO_CENTER = 90;
const int SERVO_LEFT   = 60;
const int SERVO_RIGHT  = 120;

void setup() {
  Serial.begin(115200);
  motor.setSpeed(0);
  motor.run(RELEASE);

  steering.attach(9);       // Servo signal pin
  steering.write(SERVO_CENTER);  // Center on startup
}

void loop() {
  if (Serial.available()) {
    String cmd = Serial.readStringUntil('\n');  // Read line
    cmd.trim();

    // --- Motor control ---
    if (cmd.startsWith("M")) {
      int spd = cmd.substring(2).toInt();  // Example: "M 180"
      spd = constrain(spd, 0, 255);
      motor.setSpeed(spd);
      motor.run(FORWARD);
    }

    else if (cmd == "STOP") {
      motor.setSpeed(0);
      motor.run(RELEASE);
    }

    // --- Steering control ---
    else if (cmd.startsWith("S")) {
      int angle = cmd.substring(2).toInt();  // Example: "S 120"
      angle = constrain(angle, 60, 120);     // protect servo range
      steering.write(angle);
    }

    else if (cmd == "LEFT") {
      steering.write(SERVO_LEFT);
    }

    else if (cmd == "RIGHT") {
      steering.write(SERVO_RIGHT);
    }
  }
}

```
# WRO 2025 – Vision → Arduino High-Level Control (Obstacle Challenge)

> Raspberry Pi = vision + strategy hints.
> Arduino = motors/servo + safety + **all** reversing + **full ultrasonic parking**.

This repo contains a single Python script for Raspberry Pi that detects the mat line (orange/blue), red/green pillars, and the magenta start section. It streams **high-level commands** to an Arduino over USB serial. Your Arduino sketch executes motion, avoidance, and the complete parking maneuver using six ultrasonic sensors.

---

## Features

* **Line tracking** (orange/blue) → normalized lane offset `[-1…+1]`
* **Pillar detection** (red/green) → keep-side hints (`KEEP LEFT/RIGHT`)
* **Lap counting** by magenta start section → 3 laps then `MODE PARK`
* **Robust colors**: auto-detects camera channel order (RGB vs BGR) & locks
* **WRO start flow**: waits for a **Start button** (GPIO 17) or Enter
* **Serial handshake**: waits for Arduino `RDY`, then sends `GO`, `MODE RACE`
* **Rate-limited serial**: dedupes lines to avoid flooding the Arduino
* **Heartbeat** in Park mode so Arduino watchdog stays happy
* **Graceful shutdown**: on quit/Ctrl-C sends `STOP` and cleans up

---

## System Architecture

```
PiCamera2 + OpenCV (Pi)
     │
     ├─ Detect line / pillars / magenta
     │
     ├─ Compute lane offset & lap state
     │
USB  │  ASCII protocol (newline-terminated)
     ▼
Arduino (AFMotor + Servo + 6x HC-SR04)
     ├─ State machine: RACE → PARK_* → HOLD
     ├─ Reversing & safety bubbles
     └─ Full parallel parking (ultrasonic only)
```

## 🔌 Serial Protocol (Pi → Arduino)

| Command | Args | Purpose |
| --- | --- | --- |
| `GO` | – | Start session after Arduino prints `RDY` |
| `MODE RACE`  | – | Normal lap running |
| `MODE PARK`  | – | Enter parking state machine (Arduino-only control) |
| `DRIVE o s`  | `o∈[-1..1]`, `s∈[0..255]` | Lane offset (left− / right+), speed hint |
| `KEEP LEFT`  | – | Temporary bias away from a **green** pillar |
| `KEEP RIGHT` | – | Temporary bias away from a **red** pillar |
| `HB` | – | Heartbeat (keeps Arduino watchdog alive) |
| `STOP` | – | Emergency stop on exit |

> The Arduino should **clamp** speeds by local clearance, and **own** all reversing/safety.

## ⚙️ Config You’ll Touch First

In the Python file:

```python
HEADLESS = False        # True if running over SSH without a GUI
LINE_MODE = "orange"    # or "blue" depending on your mat
DEBUG_OVERLAY = True    # on-screen HUD (disable for max performance)
START_PIN = 17          # GPIO start button (falls back to Enter if missing)
```

**HSV thresholds** live in `color_ranges` and are already tuned wide for venue lighting.

---

## Quick Start

1. **Pi packages**

```bash
sudo apt update
sudo apt install -y python3-picamera2 python3-opencv python3-numpy python3-serial
```

2. **Wire Start button** (optional, WRO-friendly)
   BCM **GPIO 17 (pin 11)** → button → **GND**.

3. **Upload Arduino sketch** (the one you built from our previous step).
   It must print `RDY` on boot and implement the protocol above.

4. **Run the Pi script**

```bash
python3 pi_vision_obstacle_highlevel.py
```

* Window opens (unless `HEADLESS=True`)
* Waits for Start (button or Enter)
* Waits for Arduino `RDY`, then sends `GO`, `MODE RACE`

---

## How the Vision Works (Pi)

### 1) Channel-order auto-detect

Some PiCamera2 pipelines deliver memory as RGB, others as BGR. Feeding the wrong order to HSV makes orange look blue, etc.
**Solution**: for \~18 frames, the script tries **both** mappings—“as-is” vs “RGB→BGR swap”—and **scores** which one makes your selected **line color** (orange or blue) dominate. It then **locks** the winner for the rest of the run.

```text
frame (RGB888 ndarray)
 ├─ treat as BGR → score mapping
 └─ convert RGB→BGR → score mapping
Lock better score → use consistently (no flicker)
```

> If the preview looks mirrored/upside-down, uncomment a `cv2.flip(...)` line where indicated.

### 2) Color masks

* Light blur → HSV
* CLAHE on V channel → lighting robustness
* Wide HSV bands for: `red`, `green`, `magenta`, `orange`, `blue`, `black`
* Morph open/close for clean blobs

### 3) Line offset

* Find largest orange/blue blob → centroid `cx`
* Normalize offset: `offset = (cx - center) / (w/2)` → `[-1..+1]`
* Speed hint: slower if pillar is “near” (area threshold)

### 4) Lap counting

* When **magenta** area exceeds a threshold → you’re in the **start section**
* Count **rising edges** (entering the section)
* After seeing it **4th time** (start pass + 3 laps) → send `MODE PARK`

## Troubleshooting

**“Colors swapped (orange ↔ blue / red ↔ cyan)”**
The auto-detector handles this. If it still misclassifies in your lighting:

* Confirm `LINE_MODE` matches your mat.
* Ensure magenta and pillar colors are visible during the first \~1 second (helps the score).
* As a last resort, set `SWAP_RB = True` (legacy manual override).

**“Left/right seems reversed”**
Uncomment a horizontal flip:

```python
# frame_bgr = cv2.flip(frame_bgr, 1)  # mirror
```

**“Serial port not found”**

* Check with `ls /dev/ttyACM* /dev/ttyUSB*`
* Add user to dialout: `sudo usermod -a -G dialout $USER && sudo reboot`

**“Laggy preview”**

* Set `DEBUG_OVERLAY = False`
* Or run headless: `HEADLESS = True` (no window)

**“Arduino doesn’t start”**

* Confirm it prints `RDY` at 115200
* Close Arduino Serial Monitor (only one program can own the port)

---

### Field Tuning Cheatsheet

* **Line window**: If the bot weaves, reduce the acceptable band a bit by tightening how you map offset → speed on the **Arduino** side (PID gain & saturation).
* **Pillar near thresholds**:

  * `min_area` \~ `0.002 * (w*h)`
  * `near_area` \~ `0.004 * (w*h)`
    Increase if false positives; decrease if it reacts too late.
* **Magenta start threshold**: `start_mag_area = int(0.0035*(w*h))`
  Raise if double-counts; lower if it misses the section.

> All reversing/parking tuning is on the **Arduino** (ultrasonic thresholds and timings).

### Code Map

* **`camera_open()`** – PiCamera2 in `RGB888`, AWB warmup then lock.
* **Auto-detect block** – decides once between as-is vs `RGB→BGR`.
* **`detect_colors()`** – masks + areas (HSV, CLAHE, morph).
* **`track_line()`** – centroid + grayscale fallback.
* **`serial_open()/send_line()`** – port scan, dedupe/rate-limit writes.
* **Start button** – waits on GPIO 17 (fallback Enter).
* **Main loop** – capture → color mapping → detect → protocol out → HUD.

### Safety Notes (WRO)

* Start in a **waiting state** (one Start button).
* **No RF/BLE/Wi-Fi** during runs; USB serial is fine.
* The Arduino must ensure **no touching** magenta boundaries in parking and must keep signs within their circles (your ultrasonic parking logic should err on the safe side).
* After parking, **stop** and ignore further motion hints.

### Extending

* Add a **“mode override”** key to force `MODE PARK` manually during testing.
* Log per-frame decisions (offset, areas) to CSV for offline tune.
* Add a “cooldown” window around magenta to prevent double lap counts.

### Need a minimal Arduino simulator?

You can bench the Pi without a robot using a tiny Python script that prints `RDY`, then echos back whatever the Pi sends. Ask and I’ll drop it in as `tools/serial_echo.py`.

# 🏁 Raspberry Pi Code -  Obstacle Challenge 
```python
#!/usr/bin/env python3
"""
WRO 2025 – Vision → Arduino High-Level Control (Webcam + Parking Steering)

- Webcam via OpenCV V4L2 (/dev/video*)
- Locks exposure & white balance (v4l2-ctl) for stable HSV colors
- RACE: line-follow (orange/blue), red/green pillar hints
- START zone (magenta) lap counting with guard if starting inside zone
- PARK ALIGN: compute steering from magenta (fallback black) to align parallel; does NOT drive inside bay
- Robust: auto-fallback to NO_SERIAL when Arduino not connected
- Flags:
    --test-vision   : run camera + color detection only (skip Arduino/serial)
    --no-arduino    : force NO_SERIAL even if a port exists
    --video-index N : choose /dev/videoN (default 0)
"""
import os, sys, time, glob, subprocess, argparse, math
import cv2
import numpy as np
import serial

# ---------------------- Headless / Qt ------------------------------------------
HEADLESS = False
if HEADLESS:
    os.environ["QT_QPA_PLATFORM"] = "offscreen"
if not os.environ.get("DISPLAY"):
    HEADLESS = True
    os.environ["QT_QPA_PLATFORM"] = "offscreen"

# ---------------------- Serial --------------------------------------------------
BAUD = 115200
ser = None
_last_sent = ""
_last_tx = 0.0
NO_SERIAL = False  # set by flags or auto-detection

def serial_open(auto_ports=None, retries=6, wait_between=1.0):
    """Try to open Arduino serial; on failure, enable NO_SERIAL and continue."""
    global ser, NO_SERIAL
    if NO_SERIAL:
        print("[Pi] NO_SERIAL=True → skip serial.")
        return None
    if auto_ports is None:
        auto_ports = sorted(glob.glob("/dev/ttyACM*")) + sorted(glob.glob("/dev/ttyUSB*"))
        auto_ports = auto_ports or ["/dev/ttyACM0", "/dev/ttyUSB0"]
    for attempt in range(1, retries + 1):
        for p in auto_ports:
            try:
                print(f"[Pi] Trying {p} @ {BAUD}…")
                s = serial.Serial(p, BAUD, timeout=0.02)
                time.sleep(2.0)  # Arduino auto-reset
                ser = s
                print(f"[Pi] Connected: {p}")
                return p
            except Exception as e:
                print(f"[Pi] {p} failed: {e}")
        print(f"[Pi] Retry {attempt}/{retries} in {wait_between}s")
        time.sleep(wait_between)
    print("[Pi] WARN: No serial ports found. Using NO_SERIAL=True.")
    NO_SERIAL = True
    return None

def wait_for_arduino_ready(max_wait=17.0):
    if NO_SERIAL:
        print("[Pi] NO_SERIAL: skip RDY wait.")
        return False
    print("[Pi] Waiting for Arduino RDY…")
    t0 = time.time()
    while time.time() - t0 < max_wait:
        try:
            line = ser.readline().decode(errors="ignore").strip()
        except Exception:
            line = ""
        if line == "RDY":
            print("[Pi] Arduino RDY")
            return True
        time.sleep(0.01)
    print("[Pi] No RDY seen; continuing.")
    return False

def send_line(s: str, min_interval=0.08, dedupe=True):
    global _last_sent, _last_tx
    now = time.time()
    if dedupe and s == _last_sent and (now - _last_tx) < min_interval:
        return
    if NO_SERIAL or ser is None:
        print(f"[TX:TEST] {s}")
        _last_sent, _last_tx = s, now
        return
    try:
        ser.write((s + "\n").encode("ascii", errors="ignore"))
    except Exception as e:
        print(f"[Pi] Serial write failed: {e}")
    _last_sent, _last_tx = s, now

# ---------------------- Start Button -------------------------------------------
HAS_GPIO = False
try:
    import RPi.GPIO as GPIO
    HAS_GPIO = True
except Exception:
    HAS_GPIO = False

START_PIN = 17

def wait_for_start_button():
    if NO_SERIAL or not HAS_GPIO:
        print("[Pi] Press Enter to START…")
        try: input()
        except EOFError: pass
        return
    GPIO.setmode(GPIO.BCM)
    GPIO.setup(START_PIN, GPIO.IN, pull_up_down=GPIO.PUD_UP)
    print("[Pi] Waiting for Start button…")
    while True:
        if GPIO.input(START_PIN) == 0:
            print("[Pi] START pressed!")
            break
        time.sleep(0.01)

# ---------------------- Webcam (V4L2) ------------------------------------------
def wait_for_camera_device(timeout=15.0):
    t0 = time.time()
    while time.time() - t0 < timeout:
        if glob.glob("/dev/video*"): return True
        time.sleep(0.1)
    return False

def free_camera_nodes():
    nodes = glob.glob("/dev/video*")
    if not nodes: return
    try:
        subprocess.run(["/usr/bin/fuser", "-k"] + nodes,
                       check=False, stdout=subprocess.DEVNULL, stderr=subprocess.DEVNULL)
    except Exception:
        pass

def configure_logitech_uvc(dev="/dev/video0", exposure_abs=120, wb_temp=4000, gain=0):
    cmds = [
        ["v4l2-ctl", "-d", dev, "--set-ctrl=exposure_auto=1"],
        ["v4l2-ctl", "-d", dev, f"--set-ctrl=exposure_absolute={exposure_abs}"],
        ["v4l2-ctl", "-d", dev, "--set-ctrl=white_balance_temperature_auto=0"],
        ["v4l2-ctl", "-d", dev, f"--set-ctrl=white_balance_temperature={wb_temp}"],
    ]
    if gain is not None:
        cmds.append(["v4l2-ctl", "-d", dev, f"--set-ctrl=gain={gain}"])
    for c in cmds:
        try:
            subprocess.run(c, check=False, stdout=subprocess.DEVNULL, stderr=subprocess.DEVNULL)
        except Exception:
            pass

def camera_open_webcam(index=0, width=640, height=480, target_fps=30):
    if not wait_for_camera_device(): raise RuntimeError("[Pi] No /dev/video* found.")
    free_camera_nodes(); time.sleep(0.2)
    cap = cv2.VideoCapture(index, cv2.CAP_V4L2)
    if not cap.isOpened(): raise RuntimeError(f"[Pi] Failed to open /dev/video{index}")
    cap.set(cv2.CAP_PROP_FRAME_WIDTH,  width)
    cap.set(cv2.CAP_PROP_FRAME_HEIGHT, height)
    cap.set(cv2.CAP_PROP_FPS,         target_fps)
    cap.set(cv2.CAP_PROP_BUFFERSIZE,  2)
    t0 = time.time()
    while time.time() - t0 < 1.5:
        ok, frame = cap.read()
        if ok and frame is not None and frame.size > 0:
            print(f"[Pi] Webcam ready at {frame.shape[1]}x{frame.shape[0]}")
            return cap
        time.sleep(0.05)
    raise RuntimeError("[Pi] Webcam warmup failed")

# ---------------------- Vision (HSV masks) -------------------------------------
LINE_MODE = "orange"   # or "blue"
DEBUG_OVERLAY = False

color_ranges = {
    "red1":     ((  0,  80,  70), ( 12, 255, 255)),
    "red2":     ((168,  80,  70), (179, 255, 255)),
    "green":    (( 40,  70,  70), ( 85, 255, 255)),
    "magenta":  ((135,  80,  80), (170, 255, 255)),
    "orange":   ((  5, 120, 110), ( 22, 255, 255)),
    "blue":     (( 95, 110,  80), (135, 255, 255)),
    "black":    ((  0,   0,   0), (179,  80,  80)),
}

def preprocess_hsv(frame_bgr):
    b = cv2.GaussianBlur(frame_bgr, (5,5), 0)
    return cv2.cvtColor(b, cv2.COLOR_BGR2HSV)

def clean_mask(mask):
    k3 = cv2.getStructuringElement(cv2.MORPH_ELLIPSE, (3,3))
    k5 = cv2.getStructuringElement(cv2.MORPH_ELLIPSE, (5,5))
    mask = cv2.morphologyEx(mask, cv2.MORPH_OPEN, k3, iterations=1)
    mask = cv2.morphologyEx(mask, cv2.MORPH_CLOSE, k5, iterations=1)
    return mask

def detect_colors(frame_bgr):
    hsv = preprocess_hsv(frame_bgr)
    r1 = cv2.inRange(hsv, color_ranges["red1"][0], color_ranges["red1"][1])
    r2 = cv2.inRange(hsv, color_ranges["red2"][0], color_ranges["red2"][1])
    masks = {"red": clean_mask(cv2.bitwise_or(r1, r2))}
    for c in ["green", "magenta", "orange", "blue", "black"]:
        masks[c] = clean_mask(cv2.inRange(hsv, color_ranges[c][0], color_ranges[c][1]))
    areas = {k: int(cv2.countNonZero(v)) for k, v in masks.items()}
    return masks, areas

def centroid_from_mask(mask):
    cnts, _ = cv2.findContours(mask, cv2.RETR_EXTERNAL, cv2.CHAIN_APPROX_SIMPLE)
    if not cnts: return None
    c = max(cnts, key=cv2.contourArea)
    M = cv2.moments(c)
    if M["m00"] <= 0: return None
    return (int(M["m10"]/M["m00"]), int(M["m01"]/M["m00"]))

def track_line(frame_bgr, masks, mode):
    chosen = "orange" if mode != "blue" else "blue"
    mask = masks[chosen]
    area = cv2.countNonZero(mask)
    h, w = frame_bgr.shape[:2]
    cx = w // 2
    if area > 800:
        cen = centroid_from_mask(mask)
        if cen: cx = cen[0]
    return cx

# ---------------------- Parking Steering ---------------------------------------
def _median_angle_deg(lines):
    if lines is None or len(lines) == 0: return 0.0, 0
    angs = []
    for x1,y1,x2,y2 in lines.reshape(-1,4):
        a = math.degrees(math.atan2(y2 - y1, x2 - x1))
        while a <= -90: a += 180
        while a >   90: a -= 180
        angs.append(a)
    if not angs: return 0.0, 0
    return float(np.median(angs)), len(angs)

def parking_steer(frame_bgr, masks):
    """Return (steer [-1..1], angle_err_deg, lateral_norm) for parallel align."""
    mag = masks.get("magenta", None)
    blk = masks.get("black", None)
    use_mag = mag is not None and cv2.countNonZero(mag) > 500
    mask = mag if use_mag else blk
    if mask is None or cv2.countNonZero(mask) < 200:
        return 0.0, 0.0, 0.0
    h, w = mask.shape[:2]
    edges = cv2.Canny(mask, 50, 150)
    lines = cv2.HoughLinesP(edges, 1, np.pi/180, threshold=40, minLineLength=40, maxLineGap=12)
    ang_err, _ = _median_angle_deg(lines)
    cen = centroid_from_mask(mask)
    lateral = 0.0
    if cen: lateral = (cen[0] - (w//2)) / (w/2.0)
    k_lat, k_ang = 0.8, 0.02
    steer = float(np.clip(k_lat*lateral + k_ang*ang_err, -1.0, 1.0))
    return steer, float(ang_err), float(lateral)

# ---------------------- Main ----------------------------------------------------
def main():
    global NO_SERIAL
    ap = argparse.ArgumentParser()
    ap.add_argument("--test-vision", action="store_true")
    ap.add_argument("--no-arduino", action="store_true")
    ap.add_argument("--video-index", type=int, default=0)
    args = ap.parse_args()
    if args.test_vision or args.no_arduino: NO_SERIAL = True

    dev = f"/dev/video{args.video_index}"
    configure_logitech_uvc(dev, exposure_abs=120, wb_temp=4000, gain=0)
    cap = camera_open_webcam(index=args.video_index, width=640, height=480, target_fps=30)

    serial_open()

    if not HEADLESS:
        cv2.namedWindow("WRO FE – Vision (Webcam)", cv2.WINDOW_NORMAL)
        cv2.resizeWindow("WRO FE – Vision (Webcam)", 900, 600)

    wait_for_start_button()

    if not NO_SERIAL:
        wait_for_arduino_ready(17.0)
        t0 = time.time()
        while time.time() - t0 < 3.0:
            send_line("GO", dedupe=False)
            send_line("MODE RACE", dedupe=False)
            time.sleep(0.25)

    laps_seen = 0
    magenta_seen_last = False
    STATE = "RACE"
    left_start_zone = False
    last_hb = 0.0
    HB_PERIOD = 0.2

    PARK_ALIGN_DURATION = 4.0   # seconds of gentle parallel align driving
    PARK_SPEED = 90             # low forward speed to avoid entering bay
    park_t0 = None

    try:
        while True:
            ok, frame_bgr = cap.read()
            if not ok or frame_bgr is None or frame_bgr.size == 0:
                time.sleep(0.01); continue

            h, w = frame_bgr.shape[:2]
            center_x = w // 2

            masks, areas = detect_colors(frame_bgr)
            min_area = int(0.002 * (w*h))
            near_area = int(0.004 * (w*h))
            start_mag_area = int(0.0035 * (w*h))

            # RACE: pillar hints
            if STATE == "RACE" and not NO_SERIAL:
                if areas["red"]   > min_area:  send_line("KEEP RIGHT")
                if areas["green"] > min_area:  send_line("KEEP LEFT")

            # Lap counting with guard
            in_start = areas["magenta"] > start_mag_area
            if not in_start: left_start_zone = True
            if STATE == "RACE" and left_start_zone and in_start and not magenta_seen_last:
                laps_seen += 1
                if laps_seen >= 3 and not NO_SERIAL:
                    STATE = "PARK"
                    park_t0 = time.time()
                    send_line("MODE PARK")
            magenta_seen_last = in_start

            # Line tracking during RACE
            cx = track_line(frame_bgr, masks, LINE_MODE)
            offset_px = cx - center_x
            offset = max(-1.0, min(1.0, offset_px / (w/2.0)))
            near_pillar = (areas["red"] > near_area) or (areas["green"] > near_area)
            speed = 120 if near_pillar else 180
            if STATE == "RACE" and not NO_SERIAL:
                send_line(f"DRIVE {offset:.3f} {int(speed)}")

            # PARK: parallel alignment only (no driving inside)
            if STATE == "PARK":
                steer, ang_err, lat = parking_steer(frame_bgr, masks)
                if not NO_SERIAL:
                    now = time.time()
                    if park_t0 is None: park_t0 = now
                    if (now - park_t0) < PARK_ALIGN_DURATION:
                        send_line(f"DRIVE {steer:.3f} {int(PARK_SPEED)}")
                    else:
                        send_line("DRIVE 0.000 0")
                else:
                    # test-vision: show alignment numbers
                    print(f"[PARK] steer={steer:+.3f} ang={ang_err:+.1f}° lat={lat:+.3f}")

            # Heartbeat
            now = time.time()
            if (now - last_hb) > HB_PERIOD and not NO_SERIAL:
                send_line("HB"); last_hb = now

            # Optional preview
            if not HEADLESS:
                if DEBUG_OVERLAY:
                    cv2.putText(frame_bgr, f"STATE: {STATE}", (10, 22),
                                cv2.FONT_HERSHEY_SIMPLEX, 0.6, (0,255,0), 2)
                cv2.imshow("WRO FE – Vision (Webcam)", frame_bgr)
                if cv2.waitKey(1) & 0xFF == ord('q'):
                    break

    except KeyboardInterrupt:
        print("[Pi] Ctrl-C")
    finally:
        try: cap.release()
        except Exception: pass
        if ser:
            try: ser.close()
            except Exception: pass
        if HAS_GPIO:
            try: GPIO.cleanup()
            except Exception: pass
        if not HEADLESS:
            try: cv2.destroyAllWindows()
            except Exception: pass
        print("[Pi] Clean exit.")

if _name_ == "_main_":
    main()
```
# 🏁 Arduino Code -  Obstacle Challenge

Here’s the TL;DR of what that Arduino sketch does:

### Roles & I/O

* **Drives the robot**: controls the DC motor (Adafruit Motor Shield v1, M1) and the steering **servo on D9**.
* **Reads 6 ultrasonics** (HC-SR04):
  FC(2/A0), FLD(3/A1), FRD(5/A2), L(6/A3), R(10/A4), B(13/A5).
* **Talks to the Raspberry Pi over serial (115200)** and follows its high-level hints.

### Serial protocol (what it accepts)

* `GO` – acknowledge start (stays idle until a MODE arrives).
* `MODE RACE` – race/obstacle driving.
* `MODE PARK` – take over and execute the full parking sequence.
* `DRIVE <offset> <speed>` – lane offset `[-1..+1]` and speed hint `0..255`.
* `KEEP LEFT` / `KEEP RIGHT` – temporary bias (≈450 ms) to the left/right.
* `HB` – heartbeat (used only to keep watchdog happy).
* `STOP` – immediate emergency stop.

On boot it **prints `RDY`** so the Pi knows it’s ready.

### Safety & watchdog

* **RX watchdog** (≈400 ms): if the Pi goes silent, it stops the motor and centers the steering.
* **Immediate obstacle stops**:

  * If **front-center** < 15 cm → stop, reverse briefly, and arc away.
  * If **hard block** (<14 cm) ahead or both diagonals are very close → same avoidance.
* All reversing/avoid is done **locally** (Arduino), independent of the Pi.

### RACE mode (line following + obstacle avoidance)

* Uses the Pi’s `DRIVE offset` as the **base steering** (offset × max-steer).
* Adds a **potential-field** term from ultrasonics:

  * FC/diagonals/side/back distances repel the robot away from obstacles.
  * PD control on the lateral field for smoother steering (KP/KD tunables).
* Applies a brief **KEEP bias** (±8°) when `KEEP LEFT/RIGHT` is received.
* Speed:

  * Starts from Pi’s `speed` hint.
  * **Clamped by forward clearance** (maps clearance to min/base speed).
  * Extra slow-down if the field strongly “pushes back”.

### PARK mode (fully on Arduino, ultrasonic only)

State machine:

1. **PARK\_ALIGN** – make the car **parallel to the side wall**
   (balance L vs R distances using slow nudges and small steering).
2. **PARK\_ENTER** – **reverse with right lock** to slip into the lot
   (until back or right side gets “near”).
3. **PARK\_STRAIGHTEN** – counter-steer while reversing a bit to straighten.
4. **PARK\_CENTER** – small forward/back nudges to center between **front** and **back** walls.
5. **PARK\_HOLD** – stop, steering centered; ignore further DRIVE hints.

Each phase has **timeouts** and conservative thresholds to avoid touching boundaries.

### Steering & drive details

* **Servo**: microsecond control around 1500 µs; ±60° limit; \~11 µs/° (tunable).
* **Motor**: forward/back via Motor Shield M1; polarity invert option if wiring flips direction.
* **Loop cadence** ≈ 20 ms for smooth servo updates and responsive control.
* **Filtering**: exponential smoothing (α=0.2) on all six distance readings.

### Tuning knobs (quick ones)

* Steering gains: `KP_STEER`, `KD_STEER`, `MAX_STEER_DEG`.
* Speed policy: `BASE_SPEED`, `MIN_SPEED`, `CLEAR_*_CM`.
* Safety thresholds: `FRONT_STOP_CM`, `HARD_BLOCK_CM`.
* Parking thresholds: `ALIGN_TOL_CM`, `ENTER_*_CM`, `CENTER_*_CM`.
* Hints: `HINT_BIAS_MS` (duration) and bias magnitude (±8° in code).

### Minimal console behavior

* On boot: prints **`RDY`**.
* (Optional debug prints are in the code, commented out; you can enable them to see distances, mode, and commands.)

FULL CODE ( WITH TWEEKS) - 
```cpp
/*
  WRO 2025 – Obstacle Challenge (Arduino)
  - Motors & steering on Arduino
  - Six HC-SR04 ultrasonics for safety + parking + 5s post-exit avoid
  - High-level hints from Raspberry Pi over Serial (one-shot friendly):
      GO, MODE RACE|PARK, DRIVE <offset> <speed>, KEEP LEFT|RIGHT, HB, STOP
  Behavior:
  - EXIT_PARK: NO REVERSING. Immediately pick freer side (L/R) and hold ±60° (TURN_HOLD_MS), then POST_EXIT_AVOID (5s OA) → RACE.
  - RACE: Open-Challenge obstacle avoidance (repulsion fields). If a DRIVE arrived in the last 0.5 s, latch it and override OA briefly.
*/

#include <Servo.h>
#include <AFMotor.h>

// ---------- Pin Map ----------
#define TRIG_FC 13    // Front-Center TRIG
#define ECHO_FC A5    // Front-Center ECHO
#define TRIG_FLD 3    // Front-Left Diag TRIG
#define ECHO_FLD A1
#define TRIG_FRD 5    // Front-Right Diag TRIG
#define ECHO_FRD A2
#define TRIG_L 6      // Left TRIG
#define ECHO_L A3
#define TRIG_R 10     // Right TRIG
#define ECHO_R A4
#define TRIG_B 2      // Back TRIG
#define ECHO_B A0
#define SERVO_PIN 9   // Steering servo (D9)

// ---------- Hardware ----------
AF_DCMotor motor(1);    // M1 on L293D shield v1
Servo steering;

// ---------- Tunables ----------
const uint16_t ECHO_TIMEOUT_US   = 20000;  // ~5 m

// Steering dynamics
const int      MAX_STEER_DEG     = 60;
const float    KP_STEER          = 1.9f;
const float    KD_STEER          = 0.25f;

// Speed policy
const int      BASE_SPEED        = 230;    // normal speed (0..255)
const int      MIN_SPEED         = 130;    // minimum forward speed when narrow
const int      REVERSE_SPEED     = 160;    // reverse speed (used in safety routine)
const int      CLEAR_FAST_CM     = 90;     // >= this ahead -> allow BASE_SPEED
const int      CLEAR_SLOW_CM     = 20;     // <= this ahead -> clamp to MIN_SPEED

// Stops & safety
const int      FRONT_STOP_CM     = 15;     // stop/avoid if FC < 15 cm
const int      HARD_BLOCK_CM     = 14;     // reverse failsafe threshold
const int      SIDE_PUSH_START   = 60;     // start side repulsion within this range

// Repulsion strengths
const float    K_FRONT           = 1.9f;
const float    K_DIAG            = 1.7f;
const float    K_SIDE            = 1.6f;
const float    K_BACK            = 0.9f;

// Smoothing
const float    ALPHA_SMOOTH      = 0.20f;

// Optional: flip motor polarity without rewiring
const bool     INVERT_MOTOR      = false;

// ---------- Serial/Protocol ----------
const bool          REQUIRE_HEARTBEAT = false;   // set true to force stop if no serial
const unsigned long RX_WATCHDOG_MS    = 400;     // used only if REQUIRE_HEARTBEAT==true
const unsigned long HINT_BIAS_MS      = 450;     // KEEP LEFT/RIGHT bias duration
const int           SERBUF_LEN        = 64;

// ---------- One-shot latch (for DRIVE) ----------
const unsigned long LATCH_MS = 500;      // latch DRIVE for 0.5 s
unsigned long lastCmdMs = 0;             // millis of last DRIVE

// ---------- State (smoothed distances) ----------
float dFCf=200, dFLDf=200, dFRDf=200, dLf=200, dRf=200, dBf=200;

// PD steering memory
float prevFy = 0.0f;

// DRIVE hint from Pi (latched)
float g_offset = 0.0f; // -1..+1
int   g_speed  = 0;    // 0..255

// Hint bias (KEEP LEFT/RIGHT): -1=left bias, +1=right bias, 0=none
int   g_keepBias = 0;
unsigned long g_keepBias_until = 0;

// Serial RX tracking
char lineBuf[SERBUF_LEN];
int  lineLen = 0;
unsigned long lastRxMs = 0;

// ---------- Modes ----------
enum Mode {
  IDLE,
  EXIT_PARK,          // NOW: decide side & hold ±60°, no reversing
  RACE,
  PARK_ALIGN,
  PARK_ENTER,
  PARK_STRAIGHTEN,
  PARK_CENTER,
  PARK_HOLD,
  EMERGENCY_STOP,
  POST_EXIT_AVOID     // 5s field-only avoidance before RACE
};
Mode mode = IDLE;

// ----- Exit-Park parameters -----
const unsigned long TURN_HOLD_MS    = 600;    // hold ±60° steering

// EXIT_PARK substates
enum ExitStage { EP_DECIDE_SIDE, EP_TURN_60, EP_DONE };
ExitStage epStage = EP_DECIDE_SIDE;
bool epPreferRight = true;
unsigned long epStageStartMs = 0;

// ----- Post-exit avoidance timing -----
const unsigned long POST_EXIT_MS = 5000UL;
unsigned long postExitStartMs = 0;

// ---------- Motor stability layer ----------
int currentMotorSpeed = 0;   // 0..255 absolute magnitude
int currentMotorDir = 0;     // -1 = backward, 0 = stopped, +1 = forward

void applyMotorHardware(int speed, int dir) {
  if (speed <= 0 || dir == 0) {
    motor.setSpeed(0);
    motor.run(RELEASE);
    currentMotorSpeed = 0;
    currentMotorDir = 0;
    return;
  }
  motor.setSpeed(constrain(speed, 0, 255));
  if (INVERT_MOTOR) dir = -dir;
  if (dir > 0) motor.run(FORWARD);
  else motor.run(BACKWARD);
  currentMotorSpeed = speed;
  currentMotorDir = dir;
}

void setMotorState(int targetSpeedSigned) {
  int targetDir = 0;
  int targetSpeed = 0;
  if (targetSpeedSigned > 0) { targetDir = +1; targetSpeed = targetSpeedSigned; }
  else if (targetSpeedSigned < 0) { targetDir = -1; targetSpeed = -targetSpeedSigned; }
  else { targetDir = 0; targetSpeed = 0; }
  if (targetDir != currentMotorDir || targetSpeed != currentMotorSpeed) {
    applyMotorHardware(targetSpeed, targetDir);
  }
}

void driveForward_direct(uint8_t spd) { setMotorState(spd); }
void driveBackward_direct(uint8_t spd) { setMotorState(-int(spd)); }
void driveStop_direct() { setMotorState(0); }

// ---------- Helpers ----------
template<typename T>
T clampT(T v, T lo, T hi) { return (v < lo) ? lo : (v > hi) ? hi : v; }
inline int   clampI(int v, int lo, int hi)       { return clampT<int>(v, lo, hi); }
inline float clampF(float v, float lo, float hi) { return clampT<float>(v, lo, hi); }

long readDistanceOnce(uint8_t trig, uint8_t echo) {
  pinMode(trig, OUTPUT);
  pinMode(echo, INPUT);
  digitalWrite(trig, LOW);  delayMicroseconds(2);
  digitalWrite(trig, HIGH); delayMicroseconds(10);
  digitalWrite(trig, LOW);
  unsigned long dur = pulseIn(echo, HIGH, ECHO_TIMEOUT_US);
  if (dur == 0) return 400;       // treat as far
  return (long)(dur / 58);        // us -> cm
}

long readDistanceMedian3(uint8_t trig, uint8_t echo) {
  long a = readDistanceOnce(trig, echo);
  long b = readDistanceOnce(trig, echo);
  long c = readDistanceOnce(trig, echo);
  if (a > b) { long t=a; a=b; b=t; }
  if (b > c) { long t=b; b=c; c=t; }
  if (a > b) { long t=a; a=b; b=t; }
  return b;
}

// Microsecond-precision steering
void setSteerDeg(int delta) {
  delta = clampI(delta, -MAX_STEER_DEG, MAX_STEER_DEG);
  const int center_us = 1500;
  const float us_per_deg = 11.0f;
  int pulse = center_us + (int)(delta * us_per_deg);
  steering.writeMicroseconds(clampI(pulse, 1000, 2000));
}

// map speed by clearance
int mapToSpeed(long clear_cm) {
  if (clear_cm <= CLEAR_SLOW_CM) return MIN_SPEED;
  if (clear_cm >= CLEAR_FAST_CM) return BASE_SPEED;
  float t = float(clear_cm - CLEAR_SLOW_CM) / float(CLEAR_FAST_CM - CLEAR_SLOW_CM);
  int spd = (int)(MIN_SPEED + t * (BASE_SPEED - MIN_SPEED));
  return clampI(spd, MIN_SPEED, BASE_SPEED);
}

// Compute repulsion magnitude
float repulse(float d_cm, float range_cm, float k) {
  if (d_cm >= range_cm) return 0.0f;
  float s = 1.0f - (d_cm / range_cm);
  if (s < 0) s = 0;
  return k * s;
}

// Stop → steer away → avoidance maneuver (safety)
void stopSteerAndAvoid(bool preferRight) {
  driveStop_direct();
  setSteerDeg(preferRight ? +MAX_STEER_DEG : -MAX_STEER_DEG);
  delay(120);
  driveBackward_direct(REVERSE_SPEED);
  delay(300);
  driveForward_direct(MIN_SPEED);
  delay(350);
  setSteerDeg(0);
}

// ---------- EXIT_PARK control (no reversing version) ----------
void enterExitPark() {
  mode = EXIT_PARK;
  epStage = EP_DECIDE_SIDE;        // start by deciding side immediately
  epStageStartMs = millis();
  setSteerDeg(0);
  driveStop_direct();
}

void runExitPark() {
  switch (epStage) {
    case EP_DECIDE_SIDE: {
      // Choose side with more clearance immediately (no reversing)
      epPreferRight = (dRf >= dLf);
      epStage = EP_TURN_60;
      epStageStartMs = millis();
      break;
    }

    case EP_TURN_60: {
      // Hold ±60° steering, motors stopped
      setSteerDeg(epPreferRight ? +60 : -60);
      driveStop_direct();
      if (millis() - epStageStartMs >= TURN_HOLD_MS) {
        setSteerDeg(0);
        epStage = EP_DONE;
      }
      break;
    }

    case EP_DONE: {
      // Enter 5s obstacle avoidance before RACE
      setSteerDeg(0);
      mode = POST_EXIT_AVOID;
      postExitStartMs = millis();
      break;
    }
  }
}

// ---------- Serial parsing ----------
void handleLine(char *s) {
  lastRxMs = millis();

  int n = 0;
  while (s[n]) n++;
  while (n > 0 && (s[n-1] == '\r' || s[n-1] == '\n' || s[n-1] == ' ')) { s[n-1] = 0; n--; }
  if (n == 0) return;

  if (strcmp(s, "GO") == 0) { return; }

  if (strncmp(s, "MODE ", 5) == 0) {
    char *arg = s + 5;

    if (strcmp(arg, "RACE") == 0) {
      if (mode == IDLE || mode == PARK_ALIGN || mode == PARK_ENTER ||
          mode == PARK_STRAIGHTEN || mode == PARK_CENTER || mode == PARK_HOLD ||
          mode == EMERGENCY_STOP) {
        enterExitPark();
      } else {
        mode = RACE;
        setSteerDeg(0);
      }
      g_keepBias = 0; g_keepBias_until = 0;
      return;
    }

    if (strcmp(arg, "PARK") == 0) {
      g_keepBias = 0; g_keepBias_until = 0;
      mode = PARK_ALIGN;
      return;
    }
  }

  if (strncmp(s, "DRIVE ", 6) == 0) {
    float o; int sp;
    if (sscanf(s + 6, "%f %d", &o, &sp) == 2) {
      g_offset = clampF(o, -1.0f, 1.0f);
      g_speed  = clampI(sp, 0, 255);
      lastCmdMs = millis();                 // latch timestamp
    }
    return;
  }

  if (strcmp(s, "KEEP LEFT") == 0) {
    g_keepBias = -1; g_keepBias_until = millis() + HINT_BIAS_MS;
    return;
  }
  if (strcmp(s, "KEEP RIGHT") == 0) {
    g_keepBias = +1; g_keepBias_until = millis() + HINT_BIAS_MS;
    return;
  }

  if (strcmp(s, "HB") == 0) { return; }

  if (strcmp(s, "STOP") == 0) {
    mode = EMERGENCY_STOP;
    driveStop_direct();
    setSteerDeg(0);
    return;
  }
}

void pumpSerial() {
  while (Serial.available()) {
    char c = Serial.read();
    if (c == '\n') {
      lineBuf[lineLen] = 0;
      handleLine(lineBuf);
      lineLen = 0;
    } else {
      if (lineLen < SERBUF_LEN - 1) {
        lineBuf[lineLen++] = c;
      } else {
        lineLen = 0;
      }
    }
  }
}

// ---------- Parking helpers (kept, unused unless you use PARK modes) ----------
const int ALIGN_TOL_CM       = 3;   // |L-R| below this => parallel
const int ALIGN_SPEED        = 120;

const int ENTER_BACK_NEAR_CM = 22;  // when back gets this close, start straighten
const int ENTER_SIDE_NEAR_CM = 18;  // when right side close during angle-in

const int STRAIGHT_TOL_CM    = 3;   // |L-R| small again => straight
const int CENTER_FRONT_CM    = 18;  // try to center between front/back ~ this
const int CENTER_BACK_CM     = 18;

unsigned long phaseStartMs = 0;

void enterPhase(Mode m) {
  mode = m;
  phaseStartMs = millis();
}

// ---------- Setup ----------
void setup() {
  Serial.begin(115200);
  delay(50);

  steering.attach(SERVO_PIN);
  setSteerDeg(0);

  currentMotorSpeed = 0;
  currentMotorDir = 0;
  motor.setSpeed(0);
  motor.run(RELEASE);

  dFCf  = readDistanceMedian3(TRIG_FC,  ECHO_FC);
  dFLDf = readDistanceMedian3(TRIG_FLD, ECHO_FLD);
  dFRDf = readDistanceMedian3(TRIG_FRD, ECHO_FRD);
  dLf   = readDistanceMedian3(TRIG_L,   ECHO_L);
  dRf   = readDistanceMedian3(TRIG_R,   ECHO_R);
  dBf   = readDistanceMedian3(TRIG_B,   ECHO_B);

  Serial.println("RDY");
  lastRxMs = millis();
}

// ---------- Main Loop ----------
void loop() {
  // 0) Serial & optional watchdog
  pumpSerial();

  if (REQUIRE_HEARTBEAT) {
    if (mode != EMERGENCY_STOP && !(mode == EXIT_PARK && epStage == EP_TURN_60)) {
      if (millis() - lastRxMs > RX_WATCHDOG_MS) {
        driveStop_direct();
        setSteerDeg(0);
      }
    }
  }

  // 1) Read & smooth ultrasonics
  long dFC  = readDistanceMedian3(TRIG_FC,  ECHO_FC);
  long dFLD = readDistanceMedian3(TRIG_FLD, ECHO_FLD);
  long dFRD = readDistanceMedian3(TRIG_FRD, ECHO_FRD);
  long dL   = readDistanceMedian3(TRIG_L,   ECHO_L);
  long dR   = readDistanceMedian3(TRIG_R,   ECHO_R);
  long dB   = readDistanceMedian3(TRIG_B,   ECHO_B);

  dFCf  = ALPHA_SMOOTH * dFC  + (1 - ALPHA_SMOOTH) * dFCf;
  dFLDf = ALPHA_SMOOTH * dFLD + (1 - ALPHA_SMOOTH) * dFLDf;
  dFRDf = ALPHA_SMOOTH * dFRD + (1 - ALPHA_SMOOTH) * dFRDf;
  dLf   = ALPHA_SMOOTH * dL   + (1 - ALPHA_SMOOTH) * dLf;
  dRf   = ALPHA_SMOOTH * dR   + (1 - ALPHA_SMOOTH) * dRf;
  dBf   = ALPHA_SMOOTH * dB   + (1 - ALPHA_SMOOTH) * dBf;

  // 2) Global immediate safety — works in any mode (except during the brief turn)
  if (!(mode == EXIT_PARK && epStage == EP_TURN_60) && mode != EMERGENCY_STOP) {
    if (dFCf < FRONT_STOP_CM) {
      bool freerRight = (dRf > dLf);
      stopSteerAndAvoid(freerRight);
      delay(20);
      return;
    }
    if (dFCf < HARD_BLOCK_CM || (dFLDf < HARD_BLOCK_CM && dFRDf < HARD_BLOCK_CM)) {
      bool freerRight = (dRf > dLf);
      stopSteerAndAvoid(freerRight);
      delay(20);
      return;
    }
  }

  // 3) Mode behaviors
  switch (mode) {
    case IDLE: {
      driveStop_direct();
      setSteerDeg(0);
      break;
    }

    case EXIT_PARK: {
      runExitPark();
      break;
    }

    case POST_EXIT_AVOID: {
      // Field-only obstacle avoidance for 5s (ignores Pi DRIVE offset)
      float Fx = 0, Fy = 0;

      float fFC  = repulse(dFCf,  CLEAR_FAST_CM, K_FRONT);   Fx += -fFC;
      float fFLD = repulse(dFLDf, CLEAR_FAST_CM, K_DIAG);
      float fFRD = repulse(dFRDf, CLEAR_FAST_CM, K_DIAG);
      const float c45 = 0.70710678f;
      Fx += -fFLD * c45;   Fy += -fFLD * c45;
      Fx += -fFRD * c45;   Fy += +fFRD * c45;

      float fL = repulse(dLf, SIDE_PUSH_START, K_SIDE);
      float fR = repulse(dRf, SIDE_PUSH_START, K_SIDE);
      Fy += -fL;  Fy += +fR;

      float fB = repulse(dBf, SIDE_PUSH_START, K_BACK);      Fx += +fB;

      float Fy_dot = Fy - prevFy;  prevFy = Fy;
      float steer_from_fields = (KP_STEER * Fy * 30.0f) + (KD_STEER * Fy_dot * 30.0f);
      int steerDeg = (int)clampF(steer_from_fields, -(float)MAX_STEER_DEG, (float)MAX_STEER_DEG);
      setSteerDeg(steerDeg);

      long diagAvg = (long)((dFLDf + dFRDf) * 0.5f);
      long forwardClear = min((long)dFCf, diagAvg);
      int spd = mapToSpeed(forwardClear);
      if (Fx < -1.2f) spd = max(spd - 50, MIN_SPEED);

      if (spd <= 0) driveStop_direct();
      else driveForward_direct(spd);

      // Seamless handoff to RACE
      if (millis() - postExitStartMs >= POST_EXIT_MS) {
        prevFy = 0.0f;      // avoid PD spike on the first RACE tick
        mode = RACE;
      }
      break;
    }

    case RACE: {
      // ---- Open-Challenge obstacle avoidance baseline ----
      float Fx = 0, Fy = 0;
      float fFC  = repulse(dFCf,  CLEAR_FAST_CM, K_FRONT);
      Fx += -fFC;
      float fFLD = repulse(dFLDf, CLEAR_FAST_CM, K_DIAG);
      float fFRD = repulse(dFRDf, CLEAR_FAST_CM, K_DIAG);
      const float c45 = 0.70710678f;
      Fx += -fFLD * c45;   Fy += -fFLD * c45;
      Fx += -fFRD * c45;   Fy += +fFRD * c45;
      float fL = repulse(dLf, SIDE_PUSH_START, K_SIDE);
      float fR = repulse(dRf, SIDE_PUSH_START, K_SIDE);
      Fy += -fL;
      Fy += +fR;
      float fB = repulse(dBf, SIDE_PUSH_START, K_BACK);
      Fx += +fB;

      float Fy_dot = Fy - prevFy; prevFy = Fy;
      float steer_from_fields = (KP_STEER * Fy * 30.0f) + (KD_STEER * Fy_dot * 30.0f);
      int   steerDeg_OA = clampI((int)steer_from_fields, -MAX_STEER_DEG, MAX_STEER_DEG);

      long diagAvg = (long)((dFLDf + dFRDf) * 0.5f);
      long forwardClear = min((long)dFCf, diagAvg);
      int spd_OA = mapToSpeed(forwardClear);
      if (Fx < -1.2f) spd_OA = max(spd_OA - 50, MIN_SPEED);

      // ---- Pi latch override (0.5 s after DRIVE) ----
      bool latchActive = (millis() - lastCmdMs) <= LATCH_MS;
      float steer_from_offset = g_offset * MAX_STEER_DEG;

      int bias = 0;
      if (g_keepBias != 0 && (long)(millis() - g_keepBias_until) < 0) {
        bias = (g_keepBias > 0) ? +8 : -8;
      } else {
        g_keepBias = 0;
      }

      int steerDeg = steerDeg_OA;
      int spd      = spd_OA;

      if (latchActive) {
        steerDeg = (int)clampF(steer_from_offset + (float)bias, -(float)MAX_STEER_DEG, (float)MAX_STEER_DEG);
        spd      = clampI(g_speed, 0, 255);
      } else {
        steerDeg = clampI(steerDeg_OA + bias, -MAX_STEER_DEG, MAX_STEER_DEG);
        // spd stays from OA
      }

      setSteerDeg(steerDeg);
      if (spd <= 0) driveStop_direct();
      else          driveForward_direct(spd);
      break;
    }

    case PARK_ALIGN: {
      int diff = (int)(dLf - dRf);
      int sgn = (diff > 0) ? -1 : +1;
      int mag = min(12, max(4, abs(diff)));
      setSteerDeg(sgn * mag);

      int spd = ALIGN_SPEED;
      if (dFCf > 25) driveForward_direct(spd);
      else if (dBf > 25) driveBackward_direct(spd-10);
      else driveStop_direct();

      if (abs(diff) <= ALIGN_TOL_CM) {
        driveStop_direct();
        setSteerDeg(0);
        enterPhase(PARK_ENTER);
      }

      if (millis() - phaseStartMs > 5000UL) {
        enterPhase(PARK_ENTER);
      }
      break;
    }

    case PARK_ENTER: {
      setSteerDeg(+MAX_STEER_DEG);
      if (dBf > ENTER_BACK_NEAR_CM && dRf > ENTER_SIDE_NEAR_CM) {
        driveBackward_direct(REVERSE_SPEED);
      } else {
        driveStop_direct();
        enterPhase(PARK_STRAIGHTEN);
      }
      if (millis() - phaseStartMs > 4000UL) {
        enterPhase(PARK_STRAIGHTEN);
      }
      break;
    }

    case PARK_STRAIGHTEN: {
      setSteerDeg(-MAX_STEER_DEG);
      if (dBf > 16) driveBackward_direct(MIN_SPEED);
      else driveStop_direct();

      int diff = (int)(dLf - dRf);
      if (abs(diff) <= STRAIGHT_TOL_CM || millis() - phaseStartMs > 2000UL) {
        driveStop_direct();
        setSteerDeg(0);
        enterPhase(PARK_CENTER);
      }
      break;
    }

    case PARK_CENTER: {
      bool front_ok = (dFCf >= CENTER_FRONT_CM - 2) && (dFCf <= CENTER_FRONT_CM + 6);
      bool back_ok  = (dBf >= CENTER_BACK_CM - 2)  && (dBf <= CENTER_BACK_CM + 6);

      if (!front_ok && dFCf > CENTER_FRONT_CM + 6 && dFCf > 14) {
        setSteerDeg(0);
        driveForward_direct(MIN_SPEED);
      } else if (!back_ok && dBf > CENTER_BACK_CM + 6 && dBf > 14) {
        setSteerDeg(0);
        driveBackward_direct(MIN_SPEED);
      } else {
        driveStop_direct();
      }

      if (front_ok && back_ok) {
        enterPhase(PARK_HOLD);
      }
      if (millis() - phaseStartMs > 3000UL) {
        enterPhase(PARK_HOLD);
      }
      break;
    }

    case PARK_HOLD: {
      driveStop_direct();
      setSteerDeg(0);
      break;
    }

    case EMERGENCY_STOP: {
      driveStop_direct();
      setSteerDeg(0);
      break;
    }
  }

  // Loop timing ~20ms for smooth servo updates
  delay(20);
}

```
```bash
cd src/
python3 wro.py sim                      # Run in simulator
python3 wro.py hsv_tuner                # Adjust HSV thresholds
python3 wro.py cam --dry-run            # Camera mode without motors
python3 wro.py cam --port /dev/ttyACM0 --baud 115200  # Full deployment with Arduino

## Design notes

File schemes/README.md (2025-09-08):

# Electromechanical Diagrams

(Designed By Kushal)

This folder documents the **wiring, control logic, and behavior** of our WRO Future Engineers vehicle.  
The diagrams show how the **Raspberry Pi (vision + decision-making)**, **Arduino (actuator control)**, and **sensors/motors** all work together.  
At a high level:
- The **Raspberry Pi** runs computer vision and calculates corrections using **PD Control**.  
- A **Finite State Machine (FSM)** decides when to switch between lane following, obstacle avoidance, turning, and parking.  
- The **Arduino** executes commands from the Pi, controlling motors, servo steering, and ultrasonic sensors.  

---

## Key Components
| Component | Role |
|---|---|
| **Arduino Uno** | Low-level controller for motor & servo control, ultrasonic sensors |
| **Raspberry Pi 3/4** | Runs OpenCV vision + high-level decision-making (FSM + PD control) |
| **Motor Driver (L293D / TB6612)**| Controls DC motor speed & direction |
| **DC Gear Motor + Servo** | Provides rear drive + steering |
| **Ultrasonic Sensors (6x HC-SR04)** | Distance sensing: front, back, sides, diagonals |
| **Li-ion Battery (11.1V 3000 mah)**| Power source for electronics & motors |

---

## PD Control (Steering)
Our vehicle uses a **Proportional–Derivative (PD) Controller** to keep itself centered in the lane.

**PD Control Formula:**
```
u(t) = Kp × e(t) + Kd × de(t)/dt
```

- **e(t)** → Lane error (distance from the center of the track)  
- **Kp (Proportional Gain)** → Corrects based on how far the car is off-center  
- **Kd (Derivative Gain)** → Corrects based on how fast the error is changing (prevents zig-zagging)  
- **u(t)** → Steering correction applied to the servo  

This ensures smooth, stable lane following without overshooting.

---

## FSM (Finite State Machine)
High-level behavior is managed by an **FSM**, which switches states depending on sensor and camera input.

**States:**
- **Lane Following** → Default, uses camera + PD control  
- **Obstacle Avoidance** → Triggered when obstacles detected  
- **Turn Around** → Used if the path is completely blocked  
- **Parking** → Activated when magenta parking zone is detected  

### State Transition Diagram

```mermaid
stateDiagram-v2
    [*] --> LaneFollowing
    LaneFollowing --> ObstacleAvoidance: Obstacle detected
    ObstacleAvoidance --> LaneFollowing: Path clear
    LaneFollowing --> Parking: Parking zone detected
    LaneFollowing --> TurnAround: Blocked path
    TurnAround --> LaneFollowing: Path clear
    Parking --> [*]
```

---

## System Architecture Flow

```mermaid
flowchart TD
    Camera["📷 Camera"] --> Pi["Raspberry Pi"]
    Pi --> Arduino["Arduino Uno"]
    Arduino --> MotorDriver["⚡ Motor Driver (L293D/TB6612)"]
    MotorDriver --> DCMotor["DC Motor"]
    Arduino --> Servo["Steering Servo"]
    Ultrasonics["Ultrasonic Sensors"] --> Arduino
```

---

## Wiring Overview

### Power Distribution
- **Li-Po Battery** → Powers entire system through voltage regulators
- **5V Regulator** → Powers Raspberry Pi, Arduino, sensors
- **Direct Battery** → Powers motor driver for maximum torque

### Communication
- **Pi ↔ Arduino**: Serial UART (TX/RX pins)
- **Arduino → Motor Driver**: Digital pins for direction, PWM for speed
- **Arduino → Servo**: PWM signal on pin 9
- **Ultrasonics → Arduino**: Trigger/Echo pins for distance measurement

### Sensor Layout
```
        [Front]
    [FL]      [FR]
[Left]          [Right]
    [BL]      [BR]
        [Back]
```
- **FL/FR**: Front-left/right diagonal sensors
- **BL/BR**: Back-left/right diagonal sensors
- **Left/Right**: Side sensors for wall detection
- **Front/Back**: Direct distance measurement

---

## Control Logic Summary

1. **Vision Processing** (Raspberry Pi)
   - Captures frames at 30 FPS
   - Detects lane lines using color masking
   - Identifies obstacles (red/green blocks)
   - Recognizes parking zones (magenta)

2. **Decision Making** (FSM on Pi)
   - Evaluates current state
   - Checks sensor data
   - Determines next action

3. **Actuation** (Arduino)
   - Receives commands via serial
   - Controls motor speed/direction
   - Adjusts steering servo
   - Monitors ultrasonic sensors

4. **Feedback Loop**
   - Sensor data sent back to Pi
   - PD controller adjusts steering
   - FSM updates state if needed

---

## Notes
- The system runs at **10Hz update rate** for real-time responsiveness
- PD gains are tuned empirically: **Kp = 0.8**, **Kd = 0.3**
- Ultrasonic sensors have **2-400cm range** with 3mm resolution
- Servo steering range: **-30° to +30°** from center

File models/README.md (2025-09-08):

## 3D Models Used 
(Designed By Kushal)

The design of the self-driving vehicle includes several custom-designed and 3D-printed components to ensure optimal component placement, secure mounting, ease of assembly, and overall mechanical stability. These models were designed using CAD tools (e.g., Creo or Fusion 360) with attention to chassis balance, sensor positioning, and modularity.

---

### 1. **Main Chassis Baseplate**

* **Description**: Flat, rectangular base with predrilled holes and slots for mounting the motor shield, Arduino Uno, Raspberry Pi, and buck converters.
* **Purpose**:

  * Central structure to hold all electronics
  * Provides wire management channels
  * Elevates the board from the ground to avoid damage
* **Design Considerations**:

  * Lightweight PLA for easy prototyping
  * Designed with symmetry for easy reassembly
  * Reinforced edges near wheel-mount zones for rigidity

---

### 2. **Motor and Wheel Mounts**

* **Description**: Custom motor brackets to hold the 12V 300 RPM DC gear motor securely.
* **Purpose**:

  * Maintain precise motor alignment for consistent straight motion
  * Absorb minor vibrations
* **Design Considerations**:

  * Mounted with screws and vibration-dampening washers
  * Shaft opening designed to match motor diameter snugly
  * Sufficient clearance provided for wire routing

---

### 3. **Ultrasonic Sensor Brackets**

* **Description**: Compact front-facing and side-mounted holders for HC-SR04 sensors.
* **Purpose**:

  * Precisely orient sensors for accurate wall-following and obstacle detection
  * Avoid blind spots due to misalignment
* **Design Considerations**:

  * 15° angle offsets for diagonal sensors
  * Cable slot integrated to keep wiring clean
  * Removable clip-on design for quick sensor replacement

---

### 4. **Raspberry Pi and Camera Mount**

* **Description**: Vertical mount structure to hold the Pi and camera module at an appropriate viewing height and angle.
* **Purpose**:

  * Ensure stable and elevated camera field-of-view for obstacle challenge vision tasks
  * Protect the Raspberry Pi from accidental impact
* **Design Considerations**:

  * Tiltable design with pre-set notches (30°, 45°, 60°) for camera angle tuning
  * Ventilation slots for passive cooling
  * Holes for M2.5 screws to secure Pi directly

---

### Design Files & Printing

* **Material**: PLA or PETG (depending on need for flexibility vs rigidity)
* **Printing Specs**:

  * Layer height: 0.2 mm
  * Infill: 25–35%
  * Supports: Enabled for Pi mount and diagonal brackets
* **Design Tools**: Creo Parametric (Primary), Fusion 360 (Prototypes)

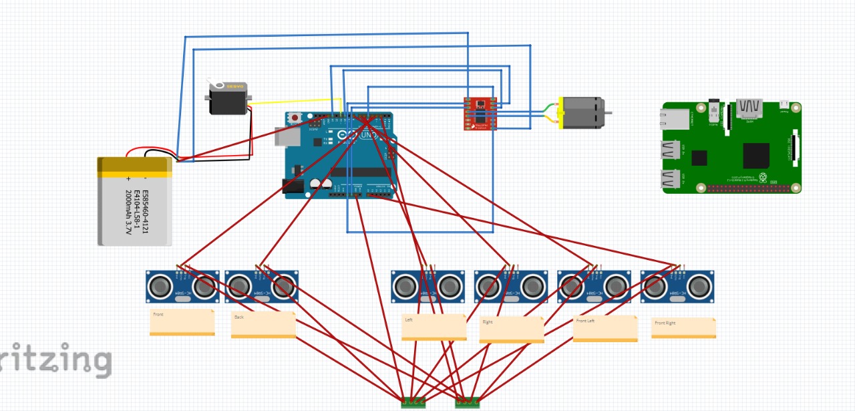
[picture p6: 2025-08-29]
schemes/Schematic Diagram.jpeg

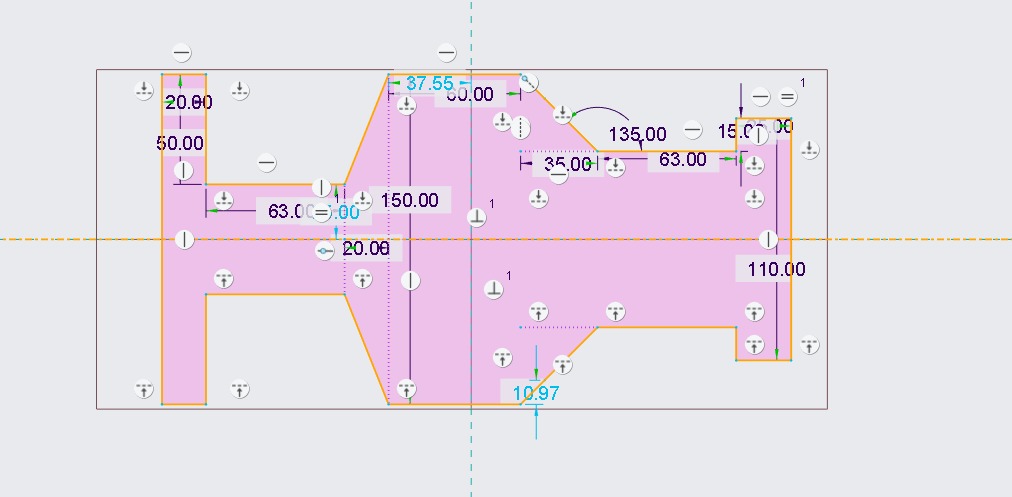
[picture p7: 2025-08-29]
models/Chassis Image.jpeg

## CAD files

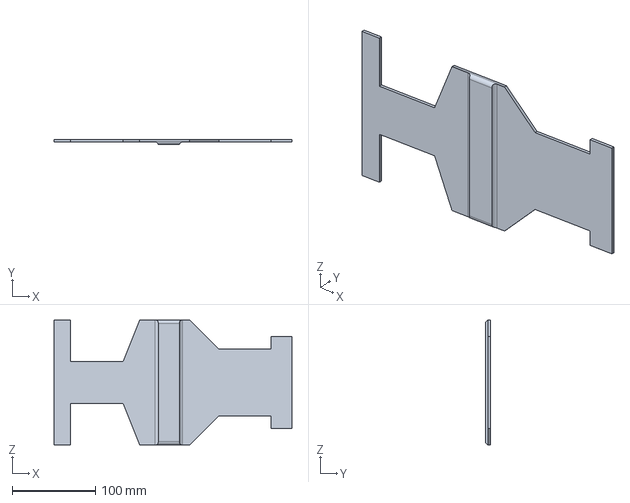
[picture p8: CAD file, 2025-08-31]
models/chassis_full.stp
286.0 x 6.00 x 150.0 mm

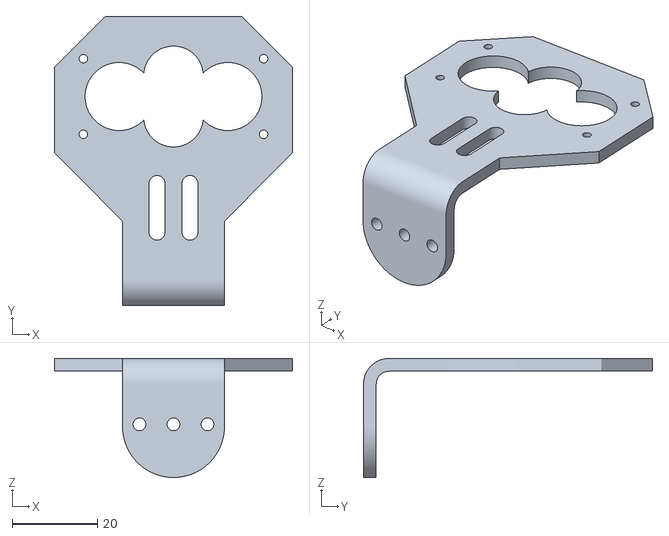
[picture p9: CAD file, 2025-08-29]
models/Ultrasonic Sensor HC-SR04 Holder.stl
56.0 x 68.0 x 28.0

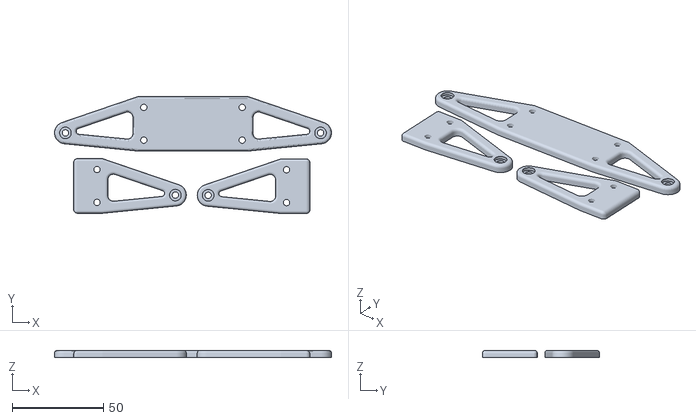
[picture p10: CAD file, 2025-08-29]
models/front_shocks.stl
152.0 x 64.2 x 4.00

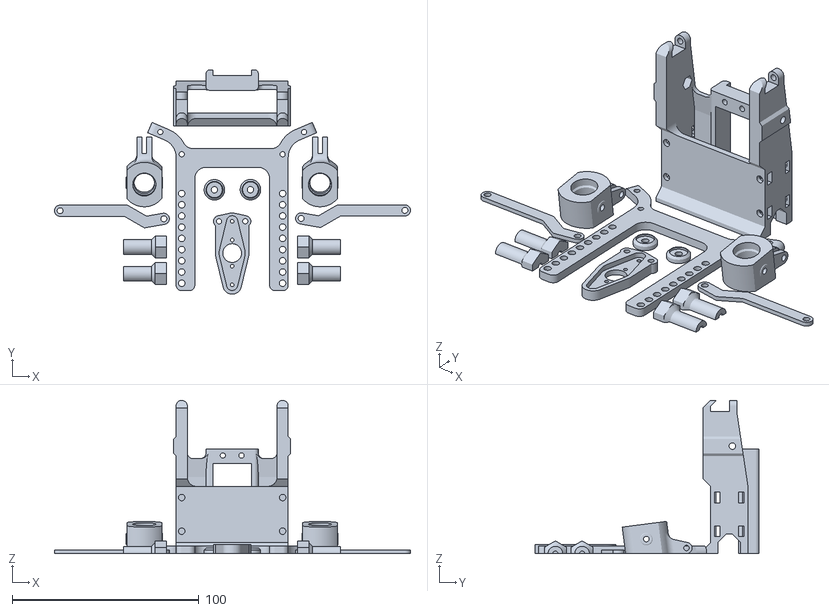
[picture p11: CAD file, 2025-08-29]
models/steering_mech.stl
190.5 x 120.1 x 82.0

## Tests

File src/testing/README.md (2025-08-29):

# Source Code

This directory contains all the code and other files used in the process of programming our WRO Future Engineers vehicle using a Raspberry Pi (vision + control) and an Arduino (motor + servo bridge).

- **wro.py** – Main Python program running on Raspberry Pi. Handles lane following, obstacle detection (red/green pillars), lap counting, and vision-guided parking between magenta bars. Supports simulation (`sim`), camera mode (`cam`), and an HSV threshold tuner (`hsv_tuner`).
- **Vision module (inside wro.py)** – Uses OpenCV to process frames, detect white lanes, colored pillars, and magenta parking bars.
- **ObstacleLogic (inside wro.py)** – Finite state machine for lane following, obstacle passing, turn-around logic, and automated parking.
- **Simulator (inside wro.py)** – Renders a virtual lane, pillars, and parking bay for testing logic without hardware. Includes keyboard controls for placing/moving obstacles.
- **HSV Tuner (inside wro.py)** – Interactive HSV slider tool to fine-tune color detection masks for white, red, green, and magenta.
- **arduino_bridge.ino** – Arduino sketch that receives serial commands from the Pi and drives:  
  - DC motor via L293/TB6612 driver (`M <int>`).  
  - Steering servo on D9 (`SUS <int>` or `S <int>`).  
  - Includes safety commands like `STOP` and a connectivity check with `PING → PONG`.

This modular structure separates **vision + decision making (Raspberry Pi)** from **low-level motor actuation (Arduino)**, making the code easier to test, debug, and extend.

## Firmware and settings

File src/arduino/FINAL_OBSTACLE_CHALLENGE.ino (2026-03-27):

/*
  WRO 2025 – Obstacle Challenge (Arduino)
  ========================================
  Dual-processor architecture: Raspberry Pi 3B+ handles vision & high-level FSM;
  Arduino Uno handles real-time actuation & proximity safety at 50 Hz.

  Fixes applied vs original repo:
    [FIX-1] REQUIRE_HEARTBEAT = true  (watchdog now active, matches paper §3.2 & S5)
    [FIX-2] Steering law: δ = KP*(o + Fy) + KD*Fy_dot  (paper Eq.12, always fused)
            Previously used a winner-takes-all latch that discarded Fy when Pi active.
    [FIX-3] BASE_SPEED = 230 (matches paper Table, §5.5)
    [FIX-4] Removed undocumented EXIT_PARK / POST_EXIT_AVOID states; parking FSM
            now matches the five-state specification in paper §6 exactly.

  Protocol (Pi → Arduino, one-directional ASCII @ 115200 baud):
    GO              – acknowledge start after Arduino prints RDY
    MODE RACE       – enter normal lap-running mode
    MODE PARK       – trigger parking FSM
    DRIVE o s       – lane offset o∈[-1,1], speed hint s∈[0,255]
    KEEP LEFT       – 450 ms left-bias (green pillar avoidance)
    KEEP RIGHT      – 450 ms right-bias (red pillar avoidance)
    HB              – heartbeat (resets 400 ms RX watchdog)
    STOP            – immediate emergency stop
*/

#include <Servo.h>
#include <AFMotor.h>

// ─── Pin Map ──────────────────────────────────────────────────────────────────
#define TRIG_FC  13   // Front-Centre TRIG
#define ECHO_FC  A5   // Front-Centre ECHO
#define TRIG_FLD  3   // Front-Left Diagonal TRIG
#define ECHO_FLD A1
#define TRIG_FRD  5   // Front-Right Diagonal TRIG
#define ECHO_FRD A2
#define TRIG_L    6   // Left TRIG
#define ECHO_L   A3
#define TRIG_R   10   // Right TRIG
#define ECHO_R   A4
#define TRIG_B    2   // Rear TRIG
#define ECHO_B   A0
#define SERVO_PIN 9   // Steering servo

// ─── Hardware ─────────────────────────────────────────────────────────────────
AF_DCMotor motor(1);  // M1 on L293D shield v1
Servo steering;

// ─── Timing ───────────────────────────────────────────────────────────────────
const uint16_t      ECHO_TIMEOUT_US   = 20000;  // ~3.4 m max range
const unsigned long LOOP_PERIOD_MS    = 20;      // 50 Hz control loop (paper §3.1)

// ─── Steering dynamics (paper §5.4, Eq.12) ───────────────────────────────────
const int   MAX_STEER_DEG = 60;
const float KP_STEER      = 1.9f;   // proportional gain
const float KD_STEER      = 0.25f;  // derivative gain

// ─── Speed policy (paper §5.5, Eq.14) ────────────────────────────────────────
// [FIX-3] BASE_SPEED corrected to 230 (was 240 in open-challenge sketch)
const int BASE_SPEED   = 230;   // smax, PWM units (≈20.8 cm/s calibrated)
const int MIN_SPEED    = 130;   // smin, PWM units (≈7.8 cm/s)
const int REVERSE_SPEED = 160;
const int CLEAR_FAST_CM = 90;   // cfast: full speed above this
const int CLEAR_SLOW_CM = 20;   // cslow: min speed below this

// ─── Safety thresholds (paper §5.2) ──────────────────────────────────────────
const int FRONT_STOP_CM = 15;   // hard stop if FC < 15 cm
const int HARD_BLOCK_CM = 14;   // hard block if FC+diagonals < 14 cm

// ─── Potential-field parameters (paper Table 3, §5.3, Eq.10-11) ──────────────
const int   SIDE_PUSH_START = 60;   // activation radius r for all sensors (cm)
const float K_FRONT         = 1.9f; // front-centre: speed regulation only
const float K_DIAG          = 1.7f; // front-left/right diagonal
const float K_SIDE          = 1.6f; // left/right side
const float K_BACK          = 0.9f; // rear (supplementary damping)

// ─── Sensor smoothing (paper §5.1, Eq.9, α=0.20) ─────────────────────────────
const float ALPHA_SMOOTH = 0.20f;

// ─── Serial / Protocol ────────────────────────────────────────────────────────
// [FIX-1] Watchdog now ENABLED to match paper §3.2 & simulation S5
const bool          REQUIRE_HEARTBEAT = true;
const unsigned long RX_WATCHDOG_MS   = 400;   // motor halts if no byte in 400 ms
const unsigned long HINT_BIAS_MS     = 450;   // KEEP LEFT/RIGHT duration (paper §5.4)
const int           SERBUF_LEN       = 64;

// ─── Motor direction ──────────────────────────────────────────────────────────
const bool INVERT_MOTOR = false;

// ─── Parking FSM timeouts (paper Table 5, §6.3) ──────────────────────────────
const unsigned long T_ALIGN      = 6000UL;  // Align phase timeout (ms)
const unsigned long T_ENTER      = 5000UL;  // Enter phase timeout (ms)
const unsigned long T_STRAIGHTEN = 3000UL;  // Straighten phase timeout (ms)
const unsigned long T_CENTRE     = 4000UL;  // Centre phase timeout (ms)
// Total worst-case = 18 s (paper §6.3)

// Parking sensor thresholds (paper Table 4)
const int ALIGN_TOL_CM     = 5;   // Δtol: |dL – dR| < 5 cm → parallel
const int ENTER_BACK_CM    = 15;  // d*_B: rear wall threshold
const int ENTER_SIDE_CM    = 12;  // d*_R: right side threshold during Enter
const int PROX_GUARD_CM    = 10;  // proximity guard: re-enter Align if FC < 10 cm
const int PARK_NUDGE_SPEED = 110; // slow nudge speed for Align/Centre phases

// ─── State ────────────────────────────────────────────────────────────────────
float dFCf=200, dFLDf=200, dFRDf=200, dLf=200, dRf=200, dBf=200;
float prevFy = 0.0f;

// Pi hints (updated by serial)
float g_offset = 0.0f;   // lane offset o ∈ [-1, 1] (paper §4.5.1)
int   g_speed  = BASE_SPEED;

int           g_keepBias       = 0;   // -1=left, +1=right, 0=none
unsigned long g_keepBias_until = 0;

// Serial bookkeeping
char          lineBuf[SERBUF_LEN];
int           lineLen  = 0;
unsigned long lastRxMs = 0;

// Mode enum – exactly five parking states from paper §6.1
enum Mode {
  IDLE,
  RACE,
  PARK_ALIGN,
  PARK_ENTER,
  PARK_STRAIGHTEN,
  PARK_CENTRE,
  PARK_HOLD,
  EMERGENCY_STOP
};
Mode mode = IDLE;

unsigned long phaseStartMs = 0;

// ─── Motor helpers ────────────────────────────────────────────────────────────
int currentSpeed = 0;
int currentDir   = 0;

void applyMotor(int speed, int dir) {
  if (speed <= 0 || dir == 0) {
    motor.setSpeed(0); motor.run(RELEASE);
    currentSpeed = 0; currentDir = 0;
    return;
  }
  motor.setSpeed(constrain(speed, 0, 255));
  bool fwd = (dir > 0) ^ INVERT_MOTOR;
  motor.run(fwd ? FORWARD : BACKWARD);
  currentSpeed = speed; currentDir = dir;
}

void driveForward(int spd)  { applyMotor(spd,  1); }
void driveBackward(int spd) { applyMotor(spd, -1); }
void driveStop()            { applyMotor(0,    0); }

// ─── Servo helper ─────────────────────────────────────────────────────────────
void setSteerDeg(int delta) {
  delta = constrain(delta, -MAX_STEER_DEG, MAX_STEER_DEG);
  steering.writeMicroseconds(1500 + (int)(delta * 11.0f));
}

// ─── Sensor reading ───────────────────────────────────────────────────────────
long readOnce(uint8_t trig, uint8_t echo) {
  digitalWrite(trig, LOW);  delayMicroseconds(2);
  digitalWrite(trig, HIGH); delayMicroseconds(10);
  digitalWrite(trig, LOW);
  unsigned long dur = pulseIn(echo, HIGH, ECHO_TIMEOUT_US);
  return (dur == 0) ? 400L : (long)(dur / 58);
}

long readMedian3(uint8_t trig, uint8_t echo) {
  long a = readOnce(trig, echo);
  long b = readOnce(trig, echo);
  long c = readOnce(trig, echo);
  if (a > b) { long t=a; a=b; b=t; }
  if (b > c) { long t=b; b=c; c=t; }
  if (a > b) { long t=a; a=b; b=t; }
  return b;
}

// ─── Speed mapping (paper Eq.14) ──────────────────────────────────────────────
int mapToSpeed(long clear_cm) {
  if (clear_cm <= CLEAR_SLOW_CM) return MIN_SPEED;
  if (clear_cm >= CLEAR_FAST_CM) return BASE_SPEED;
  float t = float(clear_cm - CLEAR_SLOW_CM) / float(CLEAR_FAST_CM - CLEAR_SLOW_CM);
  return constrain((int)(MIN_SPEED + t*(BASE_SPEED - MIN_SPEED)), MIN_SPEED, BASE_SPEED);
}

// ─── Repulsion function (paper Eq.10) ─────────────────────────────────────────
// ρ(d, r, k) = k · max(0, 1 – d/r)   [linear, matches paper exactly]
float repulse(float d_cm, float range_cm, float k) {
  if (d_cm >= range_cm) return 0.0f;
  return k * max(0.0f, 1.0f - (d_cm / range_cm));
}

// ─── Safety reverse manoeuvre (paper §5.2) ────────────────────────────────────
void safetyReverse() {
  bool freerRight = (dRf > dLf);
  driveStop();
  setSteerDeg(freerRight ? +MAX_STEER_DEG : -MAX_STEER_DEG);
  delay(120);
  driveBackward(REVERSE_SPEED);
  delay(300);
  driveForward(MIN_SPEED);
  delay(350);
  setSteerDeg(0);
}

// ─── Phase transition helper ──────────────────────────────────────────────────
void enterPhase(Mode m) {
  mode = m;
  phaseStartMs = millis();
}

// ─── Serial parsing ───────────────────────────────────────────────────────────
void handleLine(char *s) {
  lastRxMs = millis();

  // Strip trailing whitespace
  int n = strlen(s);
  while (n > 0 && (s[n-1] == '\r' || s[n-1] == '\n' || s[n-1] == ' '))
    s[--n] = 0;
  if (n == 0) return;

  if (strcmp(s, "GO") == 0) return;

  if (strncmp(s, "MODE ", 5) == 0) {
    char *arg = s + 5;
    if (strcmp(arg, "RACE") == 0) {
      mode = RACE;
      setSteerDeg(0);
      g_keepBias = 0;
      g_keepBias_until = 0;
    } else if (strcmp(arg, "PARK") == 0) {
      g_keepBias = 0;
      g_keepBias_until = 0;
      enterPhase(PARK_ALIGN);
    }
    return;
  }

  if (strncmp(s, "DRIVE ", 6) == 0) {
    float o; int sp;
    if (sscanf(s + 6, "%f %d", &o, &sp) == 2) {
      g_offset = constrain(o, -1.0f, 1.0f);
      g_speed  = constrain(sp, 0, 255);
    }
    return;
  }

  if (strcmp(s, "KEEP LEFT") == 0) {
    g_keepBias = -1;
    g_keepBias_until = millis() + HINT_BIAS_MS;
    return;
  }
  if (strcmp(s, "KEEP RIGHT") == 0) {
    g_keepBias = +1;
    g_keepBias_until = millis() + HINT_BIAS_MS;
    return;
  }

  if (strcmp(s, "HB") == 0) return;  // heartbeat, lastRxMs already updated

  if (strcmp(s, "STOP") == 0) {
    mode = EMERGENCY_STOP;
    driveStop();
    setSteerDeg(0);
    return;
  }
}

void pumpSerial() {
  while (Serial.available()) {
    char c = Serial.read();
    if (c == '\n') {
      lineBuf[lineLen] = 0;
      handleLine(lineBuf);
      lineLen = 0;
    } else if (lineLen < SERBUF_LEN - 1) {
      lineBuf[lineLen++] = c;
    } else {
      lineLen = 0;  // overflow: discard
    }
  }
}

// ─── Setup ────────────────────────────────────────────────────────────────────
void setup() {
  Serial.begin(115200);
  delay(50);

  // Configure sensor pins
  uint8_t trigs[] = {TRIG_FC, TRIG_FLD, TRIG_FRD, TRIG_L, TRIG_R, TRIG_B};
  uint8_t echos[] = {ECHO_FC, ECHO_FLD, ECHO_FRD, ECHO_L, ECHO_R, ECHO_B};
  for (int i = 0; i < 6; i++) {
    pinMode(trigs[i], OUTPUT);
    pinMode(echos[i], INPUT);
  }

  steering.attach(SERVO_PIN);
  setSteerDeg(0);

  motor.setSpeed(0);
  motor.run(RELEASE);
  currentSpeed = 0; currentDir = 0;

  // Seed smoothing filters with real readings
  dFCf  = readMedian3(TRIG_FC,  ECHO_FC);
  dFLDf = readMedian3(TRIG_FLD, ECHO_FLD);
  dFRDf = readMedian3(TRIG_FRD, ECHO_FRD);
  dLf   = readMedian3(TRIG_L,   ECHO_L);
  dRf   = readMedian3(TRIG_R,   ECHO_R);
  dBf   = readMedian3(TRIG_B,   ECHO_B);

  Serial.println("RDY");
  lastRxMs = millis();
}

// ─── Main Loop (50 Hz target) ────────────────────────────────────────────────
void loop() {
  unsigned long loopStart = millis();

  // ── 0. Serial pump & watchdog ──────────────────────────────────────────────
  pumpSerial();

  // [FIX-1] Watchdog active: halt motor + centre servo if no byte in 400 ms
  if (REQUIRE_HEARTBEAT && mode != EMERGENCY_STOP) {
    if (millis() - lastRxMs > RX_WATCHDOG_MS) {
      driveStop();
      setSteerDeg(0);  // actively centred, not held at last angle (paper §5.2)
      // Keep looping so we can recover when serial resumes
      unsigned long elapsed = millis() - loopStart;
      if (elapsed < LOOP_PERIOD_MS) delay(LOOP_PERIOD_MS - elapsed);
      return;
    }
  }

  // ── 1. Sensor acquisition + exponential smoothing (paper Eq.9, α=0.20) ─────
  long dFC  = readMedian3(TRIG_FC,  ECHO_FC);
  long dFLD = readMedian3(TRIG_FLD, ECHO_FLD);
  long dFRD = readMedian3(TRIG_FRD, ECHO_FRD);
  long dL   = readMedian3(TRIG_L,   ECHO_L);
  long dR   = readMedian3(TRIG_R,   ECHO_R);
  long dB   = readMedian3(TRIG_B,   ECHO_B);

  dFCf  = ALPHA_SMOOTH * dFC  + (1.0f - ALPHA_SMOOTH) * dFCf;
  dFLDf = ALPHA_SMOOTH * dFLD + (1.0f - ALPHA_SMOOTH) * dFLDf;
  dFRDf = ALPHA_SMOOTH * dFRD + (1.0f - ALPHA_SMOOTH) * dFRDf;
  dLf   = ALPHA_SMOOTH * dL   + (1.0f - ALPHA_SMOOTH) * dLf;
  dRf   = ALPHA_SMOOTH * dR   + (1.0f - ALPHA_SMOOTH) * dRf;
  dBf   = ALPHA_SMOOTH * dB   + (1.0f - ALPHA_SMOOTH) * dBf;

  // ── 2. Safety arbitration (paper §5.2) – not suppressible by Pi ────────────
  if (mode != EMERGENCY_STOP && mode != PARK_HOLD) {
    bool frontClose = (dFCf < FRONT_STOP_CM);
    bool hardBlock  = (dFCf < HARD_BLOCK_CM) && (dFLDf < HARD_BLOCK_CM) && (dFRDf < HARD_BLOCK_CM);
    if (frontClose || hardBlock) {
      safetyReverse();
      unsigned long elapsed = millis() - loopStart;
      if (elapsed < LOOP_PERIOD_MS) delay(LOOP_PERIOD_MS - elapsed);
      return;
    }
  }

  // ── 3. Mode behaviours ─────────────────────────────────────────────────────
  switch (mode) {

    // ──────────────────────────────────────────────────────────────────────────
    case IDLE: {
      driveStop();
      setSteerDeg(0);
      break;
    }

    // ──────────────────────────────────────────────────────────────────────────
    case RACE: {
      /*
       * [FIX-2] Steering law now correctly implements paper Eq.12:
       *   δ = KP * (o + Fy) + KD * Fy_dot
       *
       * Previously the code had a winner-takes-all latch: if a DRIVE command
       * arrived within 500 ms it used o alone; otherwise it used Fy alone.
       * The paper always sums them. Fixed here: Fy is always computed from
       * sensors; o from the latest Pi DRIVE hint (default 0 until first DRIVE).
       */

      // Compute lateral repulsion field Fy (paper Eq.11)
      // Positive Fy pushes nose right; negative pushes left.
      float fFLD = repulse(dFLDf, SIDE_PUSH_START, K_DIAG);
      float fFRD = repulse(dFRDf, SIDE_PUSH_START, K_DIAG);
      float fL   = repulse(dLf,   SIDE_PUSH_START, K_SIDE);
      float fR   = repulse(dRf,   SIDE_PUSH_START, K_SIDE);
      // Front-centre does NOT contribute lateral force; rear has reduced role
      float Fy = fFLD - fFRD + fL - fR;  // Eq.11

      // PD derivative term
      float Fy_dot = (Fy - prevFy) / (LOOP_PERIOD_MS / 1000.0f);
      prevFy = Fy;

      // Fuse Pi lane offset + potential field (paper Eq.12)
      float delta = KP_STEER * (g_offset + Fy) + KD_STEER * Fy_dot;

      // KEEP bias: additive ±8° for 450 ms (paper §5.4)
      if (g_keepBias != 0 && (long)(millis() - g_keepBias_until) < 0) {
        delta += (float)(g_keepBias > 0 ? +8 : -8);
      } else {
        g_keepBias = 0;
      }

      int steerDeg = constrain((int)delta, -MAX_STEER_DEG, MAX_STEER_DEG);
      setSteerDeg(steerDeg);

      // Speed: min of field-based and Pi hint (paper §5.5)
      int spd_sensor = mapToSpeed((long)dFCf);
      int spd = min(spd_sensor, g_speed);
      spd = constrain(spd, MIN_SPEED, BASE_SPEED);

      // Reduce speed in high-repulsion environments
      float totalRepulse = fFLD + fFRD + fL + fR;
      if (totalRepulse > 1.5f) spd = max(spd - 40, MIN_SPEED);

      driveForward(spd);
      break;
    }

    // ──────────────────────────────────────────────────────────────────────────
    // PARKING FSM – five states matching paper §6.1 / Table 4 exactly
    // ──────────────────────────────────────────────────────────────────────────

    case PARK_ALIGN: {
      /*
       * State: Align
       * Action: nudge forward/backward to balance dL ≈ dR
       * Exit:   |dL - dR| < ALIGN_TOL or timeout T_ALIGN → Enter
       * Proximity guard: if dFC < PROX_GUARD_CM → re-enter Align (reset phase timer)
       */
      if (dFCf < PROX_GUARD_CM) {
        // Proximity guard: emergency reverse, reset phase timer only
        driveStop();
        driveBackward(REVERSE_SPEED);
        delay(300);
        driveStop();
        enterPhase(PARK_ALIGN);  // resets phase timer, not global elapsed
        break;
      }

      int diff = (int)(dLf - dRf);
      // Nudge direction: if left > right, vehicle is left of bay centre → move right
      int steerBias = (diff > 0) ? -1 : +1;
      int mag = constrain(abs(diff) / 2, 4, 12);
      setSteerDeg(steerBias * mag);

      if (dFCf > 20) driveForward(PARK_NUDGE_SPEED);
      else if (dBf > 20) driveBackward(PARK_NUDGE_SPEED - 10);
      else driveStop();

      // Sensor-based exit
      if (abs(diff) <= ALIGN_TOL_CM) {
        driveStop(); setSteerDeg(0);
        enterPhase(PARK_ENTER);
        break;
      }
      // Timeout exit
      if (millis() - phaseStartMs > T_ALIGN) {
        driveStop(); setSteerDeg(0);
        enterPhase(PARK_ENTER);
      }
      break;
    }

    case PARK_ENTER: {
      /*
       * State: Enter
       * Action: reverse at +60° steering
       * Exit:   dB < d*_B OR dR < d*_R (or timeout T_ENTER) → Straighten
       */
      setSteerDeg(+MAX_STEER_DEG);

      if (dBf > ENTER_BACK_CM && dRf > ENTER_SIDE_CM) {
        driveBackward(REVERSE_SPEED);
      } else {
        driveStop();
        enterPhase(PARK_STRAIGHTEN);
        break;
      }

      if (millis() - phaseStartMs > T_ENTER) {
        driveStop();
        enterPhase(PARK_STRAIGHTEN);
      }
      break;
    }

    case PARK_STRAIGHTEN: {
      /*
       * State: Straighten
       * Action: reverse with counter-steer until δ* → 0
       * Exit:   |steer error| < 5° or timeout T_STRAIGHTEN → Centre
       */
      setSteerDeg(-MAX_STEER_DEG);

      if (dBf > 16) driveBackward(MIN_SPEED);
      else driveStop();

      int diff = (int)(dLf - dRf);
      bool straight = (abs(diff) <= ALIGN_TOL_CM);
      if (straight || millis() - phaseStartMs > T_STRAIGHTEN) {
        driveStop(); setSteerDeg(0);
        enterPhase(PARK_CENTRE);
      }
      break;
    }

    case PARK_CENTRE: {
      /*
       * State: Centre
       * Action: nudge fore/aft so dF ≈ dB (within Δtol = ALIGN_TOL_CM)
       * Exit:   |dF - dB| < Δtol or timeout T_CENTRE → Hold
       * Proximity guard applied at top of case
       */
      if (dFCf < PROX_GUARD_CM) {
        // Proximity guard: emergency reverse, re-enter Align
        driveStop();
        driveBackward(REVERSE_SPEED);
        delay(300);
        driveStop();
        enterPhase(PARK_ALIGN);  // paper Table 4: any non-terminal → Align on guard
        break;
      }

      setSteerDeg(0);
      int diff = (int)(dFCf - dBf);

      if (abs(diff) <= ALIGN_TOL_CM) {
        driveStop();
        enterPhase(PARK_HOLD);
        break;
      }

      // Nudge toward balance point
      if (diff > 0 && dBf > 14) {
        driveBackward(PARK_NUDGE_SPEED);
      } else if (diff < 0 && dFCf > 14) {
        driveForward(PARK_NUDGE_SPEED);
      } else {
        driveStop();
      }

      if (millis() - phaseStartMs > T_CENTRE) {
        driveStop();
        enterPhase(PARK_HOLD);
      }
      break;
    }

    case PARK_HOLD: {
      /*
       * State: Hold (terminal accepting state)
       * Action: motor stop, servo centred
       */
      driveStop();
      setSteerDeg(0);
      break;
    }

    // ──────────────────────────────────────────────────────────────────────────
    case EMERGENCY_STOP: {
      driveStop();
      setSteerDeg(0);
      break;
    }
  }

  // ── 4. Maintain 50 Hz loop cadence ────────────────────────────────────────
  unsigned long elapsed = millis() - loopStart;
  if (elapsed < LOOP_PERIOD_MS) delay(LOOP_PERIOD_MS - elapsed);
}

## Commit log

2025-08-29 Create RaspberryPi code
    Python project for simulating and controlling a small robot car with computer vision (OpenCV) and Arduino. Supports lane following, obstacle avoidance (red/green pillars), and auto-parking (magenta bars). Includes:
    Simulation mode for testing without hardware
    Camera mode with dry-run or Arduino serial motor control
    HSV tuner for interactive colour calibration
    Modular design with perception, control (PD), and finite state machine logic
2025-08-29 Create ArduinoCode
    Arduino Motor + Servo Bridge
    Arduino sketch to control a DC motor (via L293/TB6612) and steering servo from a Raspberry Pi over serial. Supports commands for motor speed (M), servo angle (S), servo microseconds (SUS), stop (STOP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
2025-08-31 Update ArduinoCode
